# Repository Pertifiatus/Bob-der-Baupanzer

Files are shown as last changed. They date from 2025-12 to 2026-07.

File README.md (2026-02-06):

<h1 align="center">
  <br>
  🛠️ BOB DER BAUPANZER
  <br>
</h1>

<h3 align="center">
  <em>A remote controlled and tracked vehicle with a robotic arm</em>
</h3>
---

## What is Bob?

**Bob der Baupanzer** is a DIY-Roboticsprojekt: A remote controlled tracked vehicle with a controllable arm. It is controllable via ELRS and has 3 analog Cameras which you can change to.

---

## ✨ Features

<table>
<tr>
<td width="50%">

### ELRS
- Radiomaster Boxer Transmitter
- ExpressLRS 2.4GHz Protokoll
- Latency < 10ms

</td>
<td width="50%">

### Multi-Camera System
- 3 analog FPV-Cameras
- 3D-printed & Head tracked camera gimbal
- Front-, Arm- and 3rd Person Camera
- Reltime-Videofeed

</td>
</tr>
<tr>
<td width="50%">

### Robotic arm
- NEMA17 Stepper Motors
- Cycloid gear for high torque
- NEMA17 and NEMA14 controlled front
- Precise positioning

</td>
<td width="50%">

### Tracks
- 3D-printed Links
- Robust
- Steppermotor-driven

</td>
</tr>
</table>

---

## Hardware

### Electronics-overview

<p align="center">
  Electronics Bay
</p>

### 3D-Print Components

- **Chain-links** – Muodular design for easy assembly and quick repairs
- **Video System** – Head-tracked servo gimbal
- **Robotic-arm** – Joints, Holders, Pliers
- **Cablemanagement** – Sort of magnetic gridfinity for easy wireing

---
## 📸 Galery

<p align="center">
  Entwicklungs-Setup
  Greifer Detail
  Servo Montage
</p>

<p align="center">
  Test Setup
  Kettenantrieb
  Kamera Modul
</p>

---

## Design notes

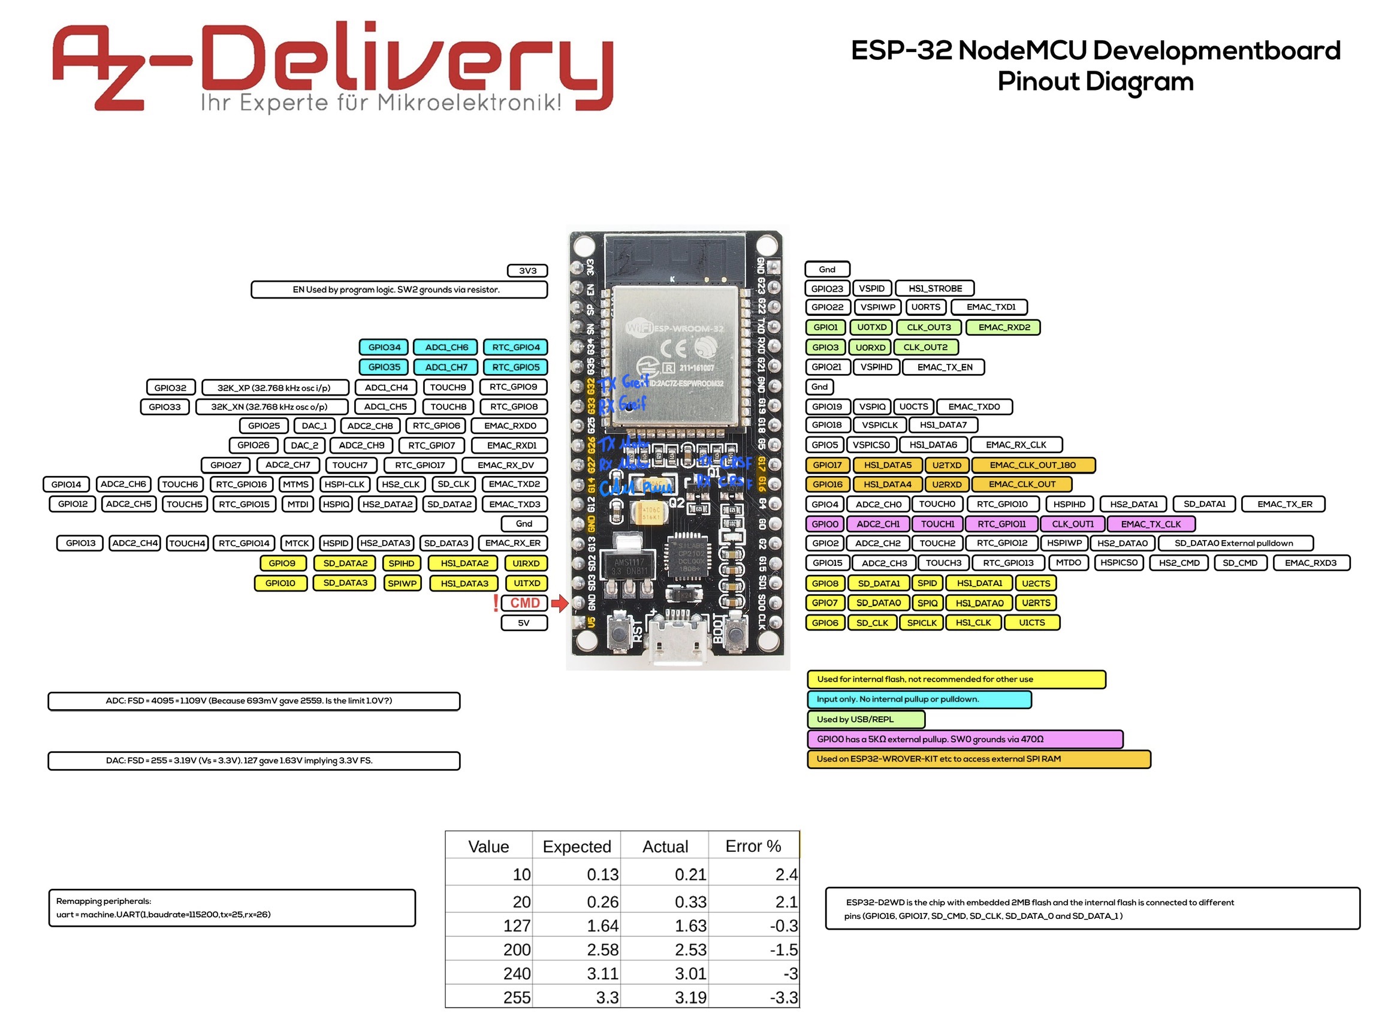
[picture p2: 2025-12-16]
Elektronik/Pinouts/ESP32-Pinout.jpg

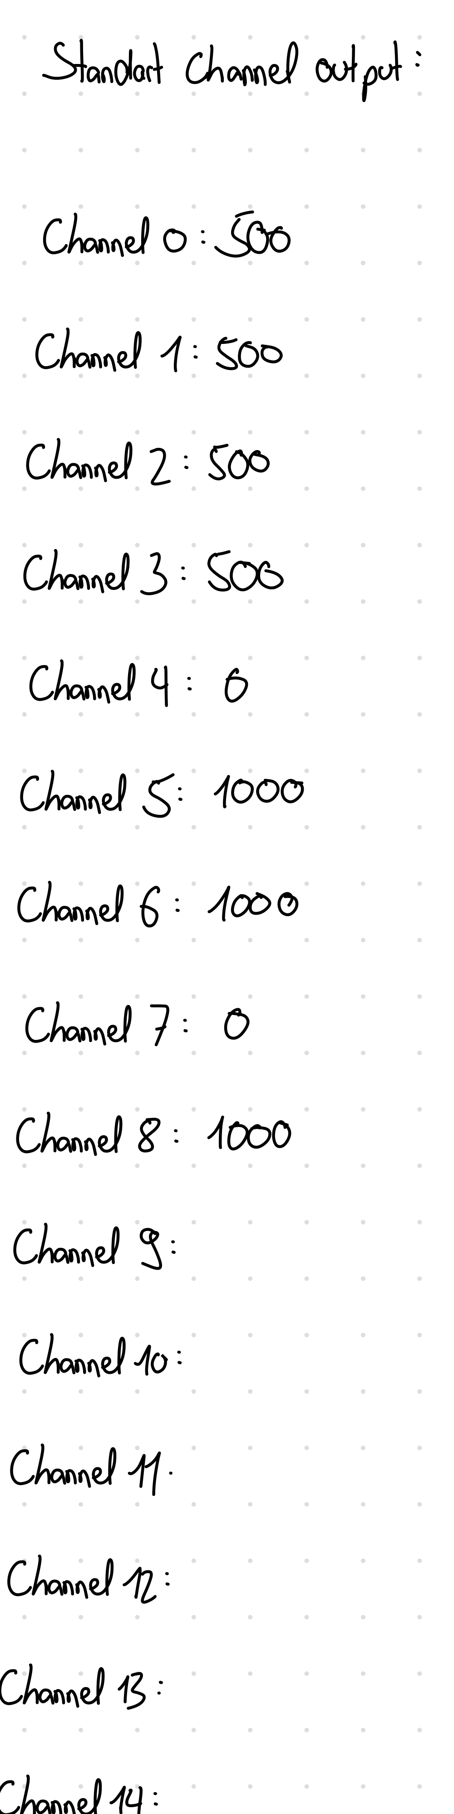
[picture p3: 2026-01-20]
Elektronik/Pinouts/PNG-Bild.png

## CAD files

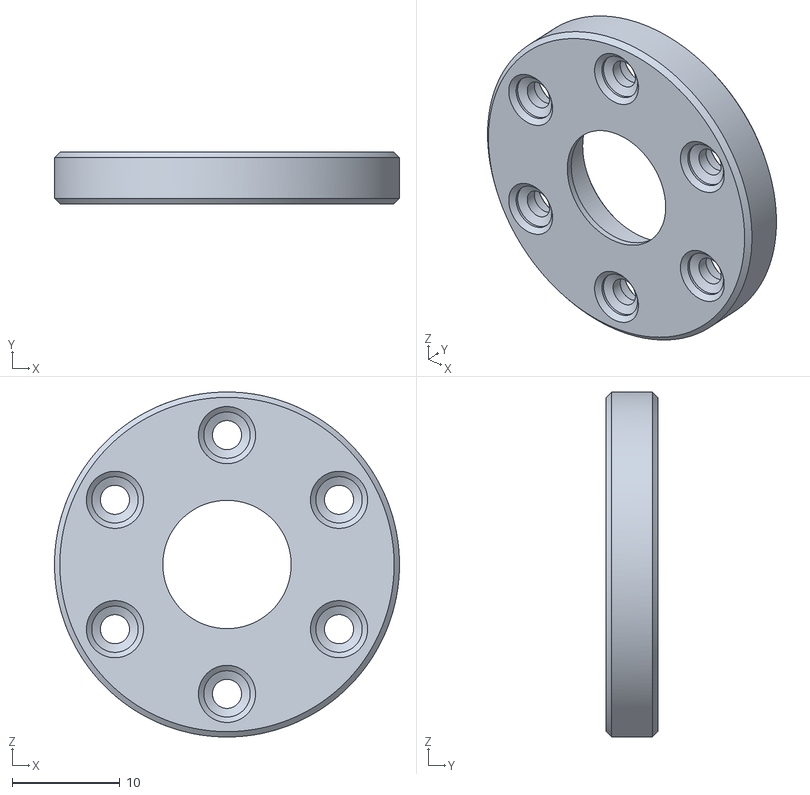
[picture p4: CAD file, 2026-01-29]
Greifarm/3dModels/Getriebe/Cycloidal 20;1/output_shaft_1--14.9.stl
32.0 x 4.80 x 32.0

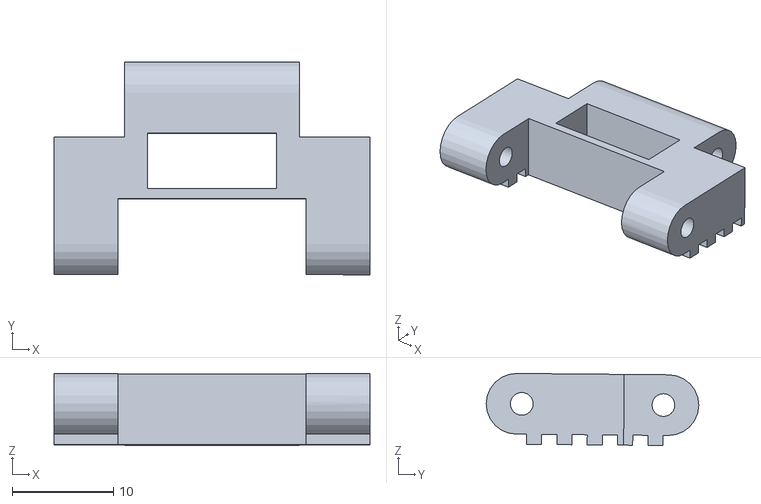
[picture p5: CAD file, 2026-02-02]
Greifarm/3dModels/Getriebe/Kette/Kette (50% Größe).STL
31.2 x 21.0 x 7.13

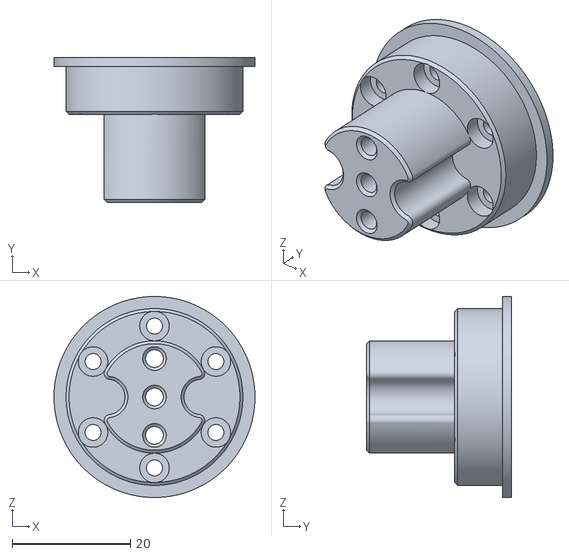
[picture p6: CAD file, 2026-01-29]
Greifarm/3dModels/Getriebe/Cycloidal 20;1/output_shaft_2--15_29.9.stl
34.0 x 24.5 x 34.0

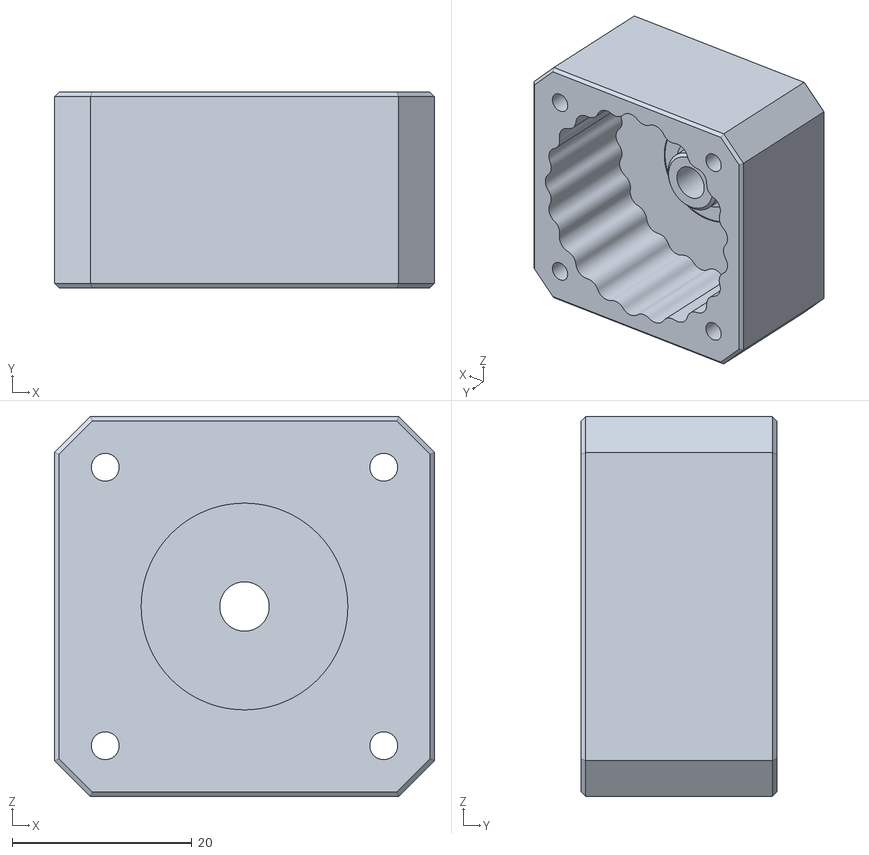
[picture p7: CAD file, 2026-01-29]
Greifarm/3dModels/Getriebe/Cycloidal 20;1/casing--9.9.stl
42.3 x 21.8 x 42.3

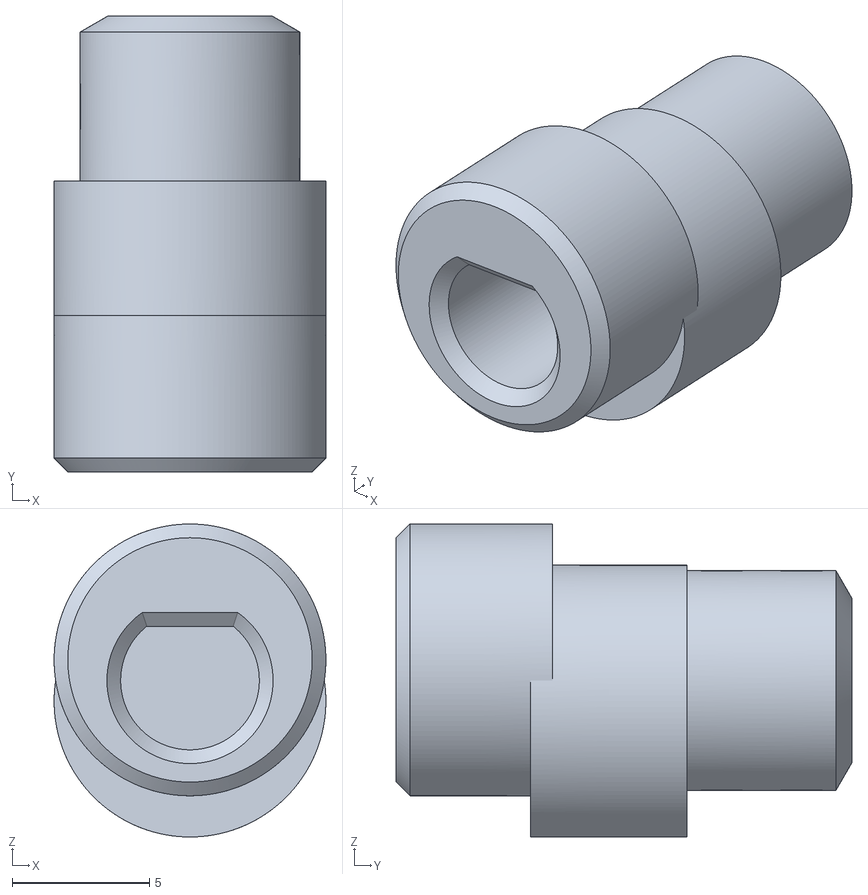
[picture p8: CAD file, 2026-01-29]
Greifarm/3dModels/Getriebe/Cycloidal 20;1/excentric_shaft--9.9.stl
9.90 x 16.6 x 11.4

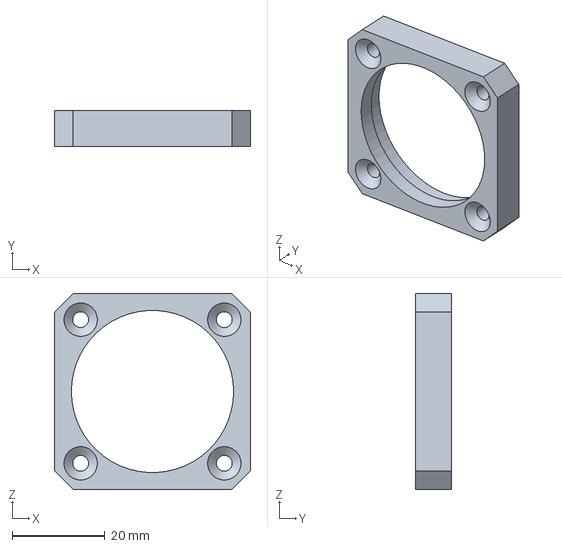
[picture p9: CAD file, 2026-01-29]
Greifarm/3dModels/Getriebe/Cycloidal 20;1/lid--36.9.stp
42.3 x 7.70 x 42.3 mm

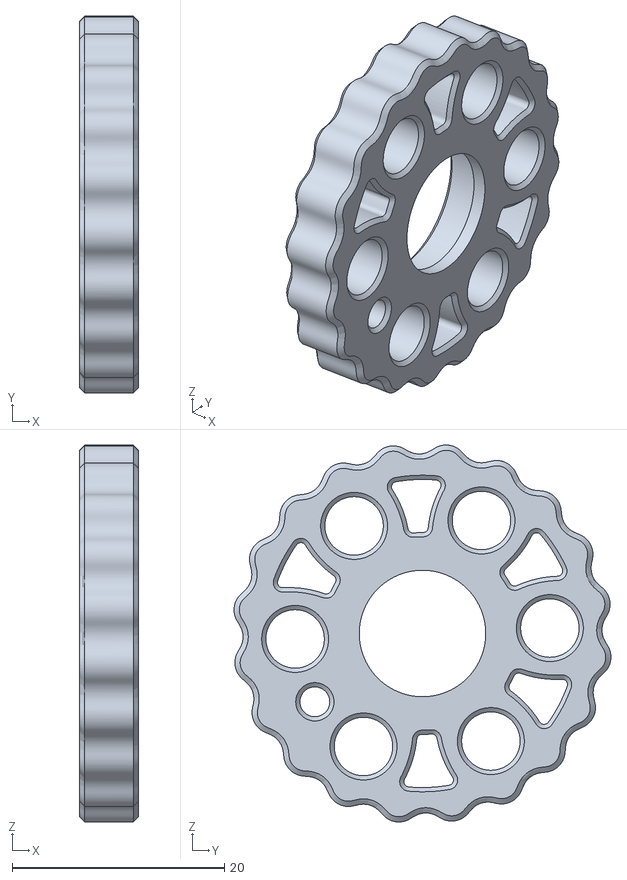
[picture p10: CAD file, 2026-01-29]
Greifarm/3dModels/Getriebe/Cycloidal 20;1/cycloidal_disk--5.5_14.9.stl
5.60 x 35.5 x 35.5

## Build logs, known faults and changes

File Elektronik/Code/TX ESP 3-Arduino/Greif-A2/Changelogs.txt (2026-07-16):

Greif-A2 Changelogs
===================

Greif-V3:
---------
- Erster vollständiger Sketch für den Greifarm-Arduino
- Startbyte 0xA2 für die Adressierung
- 8 Kanäle werden empfangen
- 4 Stepper-Motoren (X, Y, Z, A) mit AccelStepper
- "Grab" Modus eingeführt: Motoren laufen nur wenn CH4 aktiviert ist
- Enable-Steuerung über CH6
- CH7 als zusätzlicher Override zum Deaktivieren
- Failsafe mit allen Kanaelen auf 0 bzw. 1000
- Deadzone für alle 4 Achsen

Greif-V3-T0.2:
--------------
- Calibration-Funktion eingebaut! Beim Start muss man die Position kalibrieren
- "Calibrated" Flag um zu wissen ob kalibriert wurde
- Während Calibration kann man die Motoren bewegen um die Nullposition zu finden
- Calibration bestätigen mit CH4 < 500 und CH7 > 500
- Dann werden alle Stepper-Positionen auf 0 gesetzt
- vibrateMotor Funktion hinzugefügt (gibt haptisches Feedback bei Speichern)
- Failsafe-Werte auf 500 (Mittelstellung) geaendert
- Grab-Bedingung leicht angepasst (CH7 < 500 && CH4 > 500)

Greif-V4:
---------
- Stepper-Motoren sinnvoll umbenannt:
  * stepperX -> Drehachse1X
  * stepperY -> Gelenk2Y
  * stepperZ -> Gelenk3Z
  * stepperA -> Drehachse4A
- Acceleration für alle Motoren auf 2000 gesetzt (sanfteres Anfahren)
- vibrateMotor Funktion richtig implementiert (nicht mehr doppelt)
- Vibration bewegt Motor kurz hin und her als Feedback
- Calibration-Bug behoben (nur noch einmal definiert)

Greif-V4.1:
-----------
- Limit Settings für Motor X hinzugefügt

Greif-V4.2:
-----------
- Limit Settings für alle Motoren hinzugefügt
- Vibrate auch für StepperY hinzugefügt

Greif-V4.3:
-----------
- Limit Settings Bug behoben. 
- StepperCalib void hinzugefügt

Greif-V4.4:
-----------
- Individuelle Geschwindigkeitslimits und Deadzone Fix für alle Motoren

Greif-V5.3:
-----------
- Homing()-Funktion hinzugefügt (analog zur Zange, aber ohne Differenzial):
  bei CH7 > 500 und CH4 < 500 fahren alle vier Achsen einzeln mit eigener
  Homing-Geschwindigkeit (HomingSpeedX/Y/Z/A) zurueck auf Position 0, mit
  Bremszone kurz davor (nutzt die bestehenden BREMSZONE-Werte) und
  Toleranzband (HomingToleranz), in dem eine Achse als "daheim" gilt
- loop() ruft bei aktivem Homing() nicht mehr zusaetzlich Stepper() auf

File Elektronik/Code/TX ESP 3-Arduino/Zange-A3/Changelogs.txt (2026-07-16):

Zange-A3 Changelogs
===================

Zange-V0:
---------
- Minimal-Sketch nur zum Testen des Relais
- Pin 3 als Output
- Nach 5 Sekunden Verzoegerung wird das Relais eingeschaltet
- Sonst nix - nur zum Pruefen ob die Hardware funktioniert

Zange-V3:
---------
- Vollstaendiger Zangen-Sketch basierend auf Greif-Code
- Startbyte 0xA3 fuer Zangen-Adresse
- 8 Kanaele werden empfangen
- 4 Stepper-Motoren (X, Y, Z, A) wie beim Greifarm
- Grab-Bedingung: CH7 < 500 UND CH4 < 500 (beide Schalter druecken)
- Enable ueber CH6
- Failsafe auf 0/1000 Werte
- Deadzone fuer alle Achsen

Zange-V3-T0:
------------
- Calibration-Funktion eingebaut
- "Calib" Variable (0 = nicht kalibriert, 1 = kalibriert)
- Beim Start laeuft Calibration-Schleife
- Man kann Motoren bewegen und dann Position speichern
- Speichern mit CH4 > 500 und CH7 < 500
- Noch kein Feedback beim Speichern

Zange-V3-T0.1:
--------------
- Relais-Steuerung hinzugefuegt (Pin 3)
- 5 Sekunden Verzoegerung beim Start, dann Relais an
- "Relais AN" wird auf Serial ausgegeben
- vibrateMotor() Funktion fuer haptisches Feedback
- Calibration gibt jetzt "Calibration-Initiated" und "Calib-SAVE" aus
- Bei Speichern vibriert der Motor kurz zur Bestaetigung
- Debug-Ausgabe auch waehrend Calibration aktiv

Zange-V3-T0.2:
--------------
- Relais-Pin von 3 auf 2 geaendert
- "Calib" (int) zu "Calibrated" (bool) geaendert - sauberer Code
- Grab-Bedingung komplett geaendert: CH7 > 500 UND CH4 > 500
  (Jetzt muessen beide Schalter in die andere Richtung)
- Calibration-Bedingung angepasst: CH4 < 500 und CH7 > 500
- Override-Logik verbessert: CH6 > 500 und CH4 < 500 deaktiviert Motoren
- Failsafe-Werte auf 500 (Mittelstellung) geaendert statt 0
- Enable wird bei Calibration kurz aktiviert fuer die Vibration
- Mehr Kommentare im Code fuer bessere Lesbarkeit

Zange-V4:
--------------
- Endstops bei den 2 Kanälen hinzugefügt. 
- Die Schrittmotoren umbenannt

Zange-V4.1:
--------------
- StepperCalib hinzuefügt, sodass ich beim Calib keine Limits habe

Zange-V4.2:
--------------
Relais floating Pin bug gefixed

Zange-V5.4:
--------------
- Limits/Bremszonen umgestellt auf die logischen Kipp- und Greif-Achsen
  statt auf die rohen Motor-Positionen (Gelenk5X/Greifer6Y)
- Grund: Beide Motoren treiben zusammen ein Differenzial an, jeder
  Motorschritt ist eine Mischung aus Kipp- und Greif-Bewegung
  (X = Kipp+Greif, Y = -Kipp+Greif). Die alten Limits pro Motor haben
  dadurch nicht mehr die tatsaechliche Achsposition abgebildet.
- Kipp-Achse und Greif-Achse haben jetzt eigene LIMIT_MIN/MAX und
  BREMSZONE-Werte, die tatsaechliche Position wird per Differenzial-
  Kinematik aus beiden Motorpositionen zurueckgerechnet
- Homing()-Funktion vervollständigt: bei CH7 > 500 und CH4 < 500 fahren
  beide Achsen mit eigener Homing-Geschwindigkeit (HomingSpeedKipp/
  HomingSpeedGreif) zurueck auf Position 0, mit Bremszone kurz davor
  und Toleranzband (HomingToleranz), in dem die Achse als "daheim" gilt
- loop() ruft bei aktivem Homing() nicht mehr zusaetzlich Stepper() auf

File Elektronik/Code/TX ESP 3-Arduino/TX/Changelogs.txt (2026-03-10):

TX Changelogs
=============

TX-V0:
------
- Erster Test-Sketch für den TX-ESP32
- CRSF Library eingebunden für Crossfire-Empfaenger
- RX auf GPIO6, TX auf GPIO5
- Liest alle 16 Kanäle vom Empfänger
- Gibt alle Kanäle auf dem Serial Monitor aus
- TXSerial auf 9600 Baud (noch nicht benutzt)
- Nur zum Testen ob die CRSF-Verbindung funktioniert

TX-V1:
------
- Richtiges Kommunikations-Protokoll eingebaut!
- Verschiedene Start-Tokens für verschiedene Empfänger:
  * 0x01 für ESP32 (14 Kanäle)
  * 0xA1 für Arduino 1 - Motor (7 Kanäle)
  * 0xA2 für Arduino 2 - Greif (6 Kanäle)
  * 0xA3 für Arduino 3 - Zange (3 Kanäle)
- Alle 50ms wird an jeden Empfänger gesendet
- Werte werden von CRSF (172-1810) auf 0-1000 gemappt
- constrain() sorgt dafür dass Werte im Bereich bleiben
- TXSerial auf 115200 Baud, RX=20, TX=21

TX-V2:
------
- Kanal-Anzahl für A1 von 7 auf 6 reduziert
- Kanal-Anzahl für A2 von 6 auf 8 erhöht

TX-V3:
------
- Kanal-Anzahl für A3 von 3 auf 8 erhöht

TX-V4:
------
- "Failsave Modus" hinzugefügt, wenn alle Kanäle auf 0 sind, sendet der ESP keine Daten mehr an die Geräte, sodass diese in den    Failsave Modus gehen, anstatt alle Motoren schnell zu drehen

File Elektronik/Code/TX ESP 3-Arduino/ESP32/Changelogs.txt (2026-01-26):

ESP32 Changelogs
================

ESP32-V3:
---------
- Basis-Sketch für den ESP32 auf dem Fahrzeug
- Empfängt alle 14 Kanaele über Serial2 (RX=14, TX=27)
- Startbyte 0x01 für ESP32-Pakete
- Debug-Ausgabe alle 100ms auf Serial
- HeadTracker Funktion vorbereitet aber noch leer
- ESP32PWM Timer 0 reserviert

ESP32-V3.1:
-----------
- Head-Tracker implementiert!
- Zwei Servos hinzugefuegt: Pitch (Pin 25) und Sweep (Pin 26)
- Servos mit 500-2500us Pulsweite konfiguriert
- HeadTracker() Funktion liest Kanal 9 (Pitch) und Kanal 10 (Sweep)
- Werte werden von 0-1000 auf 0-180 Grad gemappt
- Debug-Intervall auf 200ms erhoeht

ESP32-V3.2:
-----------
- NeoPixel LED-Strip eingebaut! (10 LEDs an Pin 33)
- Adafruit_NeoPixel Library hinzugefuegt
- LEDs zeigen die aktuelle Sweep-Position an
  * Alle LEDs weiss, nur 3 LEDs an der aktuellen Position aus (als Positionsanzeige)
- Video-Switcher Servo an Pin 32 hinzugefuegt
- 3 Kamera-Positionen ueber CH8:
  * Position 1: 1000us
  * Position 2: 1500us
  * Position 3: 2000us
- Video() Funktion ersetzt HeadTracker() und macht beides
- LED Helligkeit auf 50 (von 255) eingestellt

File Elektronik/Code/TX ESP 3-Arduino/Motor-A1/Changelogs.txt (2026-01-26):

Motor-A1 Changelogs
===================

Motor-V1:
---------
- Erster Sketch für den Motor-Arduino
- Empfängt 7 Kanäle über Serial mit Startbyte 0xA1
- Gibt die empfangenen Werte einfach auf dem Serial Monitor aus
- Noch keine Motorsteuerung, nur zum Testen der Kommunikation

Motor-V2:
---------
- Failsafe eingebaut: Wenn 500ms keine Daten kommen, werden alle Kanäle auf 0 gesetzt
- Kanalanzahl auf 6 reduziert
- "MeineNachricht" Flag eingeführt - damit werden nur Pakete mit dem richtigen Startbyte verarbeitet
- Debug-Ausgabe läuft jetzt nur alle 100ms (schont die CPU)
- Zeigt an ob Daten empfangen werden [OK] oder Failsafe aktiv ist [!]

Motor-V3-ErsteMotor:
--------------------
- AccelStepper Library eingebunden für 4 Schrittmotoren (X, Y, Z, A)
- Enable-Pin (Pin 8) für die Treiber hinzugefuegt
- Deadzone-Funktion eingebaut damit kleine Stick-Bewegungen ignoriert werden
- Drive-Modus eingeführt: Motoren laufen nur wenn CH4 aktiviert ist
- Arming-Logik: Motoren werden automatisch aktiviert wenn die Sticks bewegt werden
- Failsafe-Werte jetzt auf Mittelstellung (500) statt 0
- Speed auf 1300 Steps/s eingestellt
- Debug-Ausgabe auskommentiert (für Performance)

Motor-V3.1:
-----------
- Keine Änderungen zu V3-ErsteMotor
- Nur aufgeräumte Version ohne zusätzliche Leerzeilen

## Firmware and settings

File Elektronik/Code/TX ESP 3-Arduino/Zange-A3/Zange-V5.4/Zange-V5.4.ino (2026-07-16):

#include <AccelStepper.h>

#define ENABLE_PIN 8
int EN = 1;    // 0=Enabled, 1=Disabled
int Grab = 0;  // Grab Status
long speedX = 0;
long speedY = 0;
long speedKipp = 0;
long speedGreif = 0;

const long MaxSpeedKipp = 600;    //SPEED... I am SPEED... Faster than fast quicker than quick... I am lightning
const long MaxSpeedGreif = 7000;  //SPEED... I am SPEED... Faster than fast quicker than quick... I am lightning
const long MaxSpeedMotor = MaxSpeedKipp + MaxSpeedGreif;  // Motor sieht im schlechtesten Fall die Summe beider Anteile

// Beide Motoren treiben zusammen ein Differenzial an: jeder Motorschritt ist eine
// Mischung aus Kipp- und Greif-Bewegung (X = Kipp+Greif, Y = -Kipp+Greif). Deshalb
// werden die Limits hier auf die zurueckgerechneten logischen Achsen angewendet und
// nicht mehr auf die rohen Motor-Positionen.
const long LIMIT_MIN_Kipp = -900;
const long LIMIT_MAX_Kipp = 900;
const long BREMSZONE_Kipp = 200;

const long LIMIT_MIN_Greif = -35000;
const long LIMIT_MAX_Greif = 10000;
const long BREMSZONE_Greif = 1000;

// Geschwindigkeiten fuers Homing (langsamer als der normale Betrieb) sowie die
// Toleranz, ab der eine Achse als "daheim" (Position 0) gilt.
const long HomingSpeedKipp = 300;
const long HomingSpeedGreif = 2000;
const long HomingToleranz = 5;

AccelStepper Gelenk5X(AccelStepper::DRIVER, 2, 5);
AccelStepper Greifer6Y(AccelStepper::DRIVER, 3, 6);

int applyDeadzone(int value, int dz) {
  return (abs(value) < dz) ? 0 : value;
}

const byte ST = 0xA3;
const int NUM_CHANNELS = 8;
int channels[NUM_CHANNELS];

unsigned long lastPacketTime = 0;
const unsigned long TimeoutFailsafe = 500;
bool failsafeActive = false;
bool Calibrated = false;

// Binärprotokoll: pro Kanal 2 Bytes (low/high, je auf 7 Bit begrenzt), damit
// alle Nutzdaten-Bytes < 0x80 bleiben - nur die Start-Bytes der Boards
// (0xA0-0xA3) haben Bit 7 gesetzt und sind so immer eindeutig vom Kanalwert
// zu unterscheiden. Dadurch ist die Frame-Länge konstant, egal ob die Kanäle
// bei 0 oder bei 1000 stehen.
const int FRAME_PAYLOAD_LEN = NUM_CHANNELS * 2;
byte frameBuffer[FRAME_PAYLOAD_LEN];
int frameIndex = 0;
bool receivingFrame = false;


void setup() {
  pinMode(4, OUTPUT);  //Relais Pin
  digitalWrite(4, 0);
  pinMode(ENABLE_PIN, OUTPUT);
  Gelenk5X.setMaxSpeed(MaxSpeedMotor);
  Gelenk5X.setAcceleration(2000);
  Greifer6Y.setMaxSpeed(MaxSpeedMotor);
  Greifer6Y.setAcceleration(2000);

  Serial.begin(250000);

  activateFailsafe();
  lastPacketTime = millis();

  delay(5000);
  digitalWrite(4, 1);
  Serial.println("Relais AN");

  Calibration();
}

void Calibration() {
  Serial.print("Calibration-Initiated");
  while (!Calibrated) {
    ReadSerial();
    static unsigned long lastDebugTime = 0;

    if (millis() - lastDebugTime > 100) {  // Nur alle 100ms Text ausgeben
      lastDebugTime = millis();
      printDebugInfo();
    }

    if (channels[4] < 500 && channels[7] > 500) {
      Gelenk5X.setCurrentPosition(0);
      Greifer6Y.setCurrentPosition(0);
      Calibrated = true;
      digitalWrite(ENABLE_PIN, 0);
      vibrateMotor(Gelenk5X, 20, 2);
      digitalWrite(ENABLE_PIN, 1);
      Serial.print("Calib-SAVE");
    } else {
      Channellogic();
      StepperCalib();
    }
  }
}

void loop() {
  ReadSerial();
  Channellogic();
  if (!Homing()) {
    Stepper();
  }
  /*
  static unsigned long lastDebugTime = 0;
  if (millis() - lastDebugTime > 100) {  // Nur alle 100ms Text ausgeben (schont die CPU)
    lastDebugTime = millis();
    printDebugInfo();
  }
  */
}


void ReadSerial() {
  while (Serial.available() > 0) {  //Wenn Serielle Daten verfügbar sind
    byte incomingByte = Serial.read();

    if (incomingByte == ST) {  //Falls unser Startbyte erkannt wird: neuen Frame beginnen
      receivingFrame = true;
      frameIndex = 0;
      continue;
    }

    if (incomingByte & 0x80) {
      // Startbyte eines anderen Boards -> unser Frame ist ungültig/beendet
      receivingFrame = false;
      continue;
    }

    if (!receivingFrame) continue;

    if (frameIndex < FRAME_PAYLOAD_LEN) {
      frameBuffer[frameIndex++] = incomingByte;
    } else {
      // Dieses Byte ist die Prüfsumme -> Frame ist komplett
      decodeFrame(incomingByte);
      receivingFrame = false;
    }
  }

  //  Failsafe Check
  if (millis() - lastPacketTime > TimeoutFailsafe) {
    if (!failsafeActive) {
      activateFailsafe();
      failsafeActive = true;
    }
  }
}

// Prüft die Prüfsumme und übernimmt bei Erfolg die Kanalwerte aus frameBuffer.
void decodeFrame(byte receivedChecksum) {
  byte checksum = 0;
  for (int i = 0; i < FRAME_PAYLOAD_LEN; i++) checksum ^= frameBuffer[i];
  checksum &= 0x7F;

  if (checksum != receivedChecksum) {
    // Frame verwerfen, da Prüfsumme nicht passt (z.B. durch Bitfehler)
    return;
  }

  // Die XOR-Prüfsumme erkennt nicht jeden Bitfehler (z.B. zwei Bitkipper an
  // derselben Position in unterschiedlichen Bytes können sich gegenseitig
  // aufheben). Als zweite Verteidigungslinie werden die dekodierten Werte
  // zusätzlich auf den gültigen Bereich 0-1000 begrenzt, damit ein durch die
  // Prüfsumme rutschender Fehler keinen Kanalwert weit außerhalb des
  // erwarteten Bereichs an die Motorsteuerung weiterreichen kann.
  for (int i = 0; i < NUM_CHANNELS; i++) {
    byte lowBits = frameBuffer[i * 2];
    byte highBits = frameBuffer[i * 2 + 1];
    channels[i] = constrain(lowBits | (highBits << 7), 0, 1000);
  }

  // Wenn Daten korrekt ankommen -> Failsafe beenden
  if (failsafeActive) {
    failsafeActive = false;
  }
  lastPacketTime = millis();  //  Timeout-Timer erneuern
}

void activateFailsafe() {

  channels[0] = 500;
  channels[1] = 500;
  channels[2] = 500;
  channels[3] = 500;
  channels[4] = 0;
  channels[5] = 1000;
  channels[6] = 1000;
  channels[7] = 0;
}

void printDebugInfo() {
  if (failsafeActive) {
    Serial.print(" [!] - Fallback: ");
  } else {
    Serial.print(" [OK] - Werte: ");
  }

  for (int i = 0; i < NUM_CHANNELS; i++) {
    Serial.print(channels[i]);
    if (i < NUM_CHANNELS - 1) Serial.print(",");
  }
  Serial.print(Grab);
  Serial.println();
}

void Channellogic() {
  long kippAnteil = map(channels[1], 0, 1000, MaxSpeedKipp, -MaxSpeedKipp);
  long greifAnteil = map(channels[2], 0, 1000, MaxSpeedGreif, -MaxSpeedGreif);

  kippAnteil = applyDeadzone(kippAnteil, MaxSpeedKipp * 0.1);
  greifAnteil = applyDeadzone(greifAnteil, MaxSpeedGreif * 0.1);

  speedKipp = kippAnteil;
  speedGreif = greifAnteil;

  speedX = kippAnteil + greifAnteil;
  speedY = -kippAnteil + greifAnteil;

  // Logik für Enable (EN)
  if (channels[6] < 500) {  //Falls Channel 6 kleiner 500 ist
    EN = 0;                 // Motor AN
  } else {
    EN = 1;  // Motor AUS
  }


  if (channels[7] > 500 && channels[4] > 500) {  //Falls Channel 7 großer 500, und Channel 4 großer 500. (Beide Switches gedrückt)
    Grab = 1;
  } else {
    Grab = 0;
  }

  if (Grab == 1) {  // Arming in Grab Action
    if (speedX != 0 || speedY != 0) {
      EN = 0;  // Wenn die Sticks nicht center sind, Motor AN
    }
  }

  if (channels[6] > 500 && channels[4] < 500) {  // Override, falls Channel gewechselt wird, während sich die Motoren drehen
    EN = 1;
  }
}

void Stepper() {
  if (Grab == 1) {
    long currentPosX = Gelenk5X.currentPosition();
    long currentPosY = Greifer6Y.currentPosition();

    // Differenzial-Kinematik umkehren (X = Kipp+Greif, Y = -Kipp+Greif), um die
    // tatsaechliche Position der beiden logischen Achsen zu bestimmen.
    long kippPos = (currentPosX - currentPosY) / 2;
    long greifPos = (currentPosX + currentPosY) / 2;

    long finalKipp = speedKipp;
    long finalGreif = speedGreif;

    //Bremszone Kipp
    if (finalKipp > 0 && (LIMIT_MAX_Kipp - kippPos) < BREMSZONE_Kipp) {
      // Bremse Richtung Plus
      finalKipp = finalKipp * (LIMIT_MAX_Kipp - kippPos) / BREMSZONE_Kipp;

    } else if (finalKipp < 0 && (kippPos - LIMIT_MIN_Kipp) < BREMSZONE_Kipp) {
      // Bremse Richtung Minus
      finalKipp = finalKipp * (kippPos - LIMIT_MIN_Kipp) / BREMSZONE_Kipp;
    }

    // Not-Stopp Sicherheitscheck
    if (kippPos >= LIMIT_MAX_Kipp && finalKipp > 0) finalKipp = 0;
    if (kippPos <= LIMIT_MIN_Kipp && finalKipp < 0) finalKipp = 0;

    //Bremszone Greif
    if (finalGreif > 0 && (LIMIT_MAX_Greif - greifPos) < BREMSZONE_Greif) {
      // Bremse Richtung Plus
      finalGreif = finalGreif * (LIMIT_MAX_Greif - greifPos) / BREMSZONE_Greif;

    } else if (finalGreif < 0 && (greifPos - LIMIT_MIN_Greif) < BREMSZONE_Greif) {
      // Bremse Richtung Minus
      finalGreif = finalGreif * (greifPos - LIMIT_MIN_Greif) / BREMSZONE_Greif;
    }

    // Not-Stopp Sicherheitscheck
    if (greifPos >= LIMIT_MAX_Greif && finalGreif > 0) finalGreif = 0;
    if (greifPos <= LIMIT_MIN_Greif && finalGreif < 0) finalGreif = 0;

    // Zurueck in die tatsaechlichen Motor-Geschwindigkeiten wandeln
    Gelenk5X.setSpeed(finalKipp + finalGreif);
    Greifer6Y.setSpeed(-finalKipp + finalGreif);

  } else {
    Gelenk5X.setSpeed(0);
    Greifer6Y.setSpeed(0);
  }
  digitalWrite(ENABLE_PIN, EN);
  Gelenk5X.runSpeed();
  Greifer6Y.runSpeed();
}

// Faehrt beide Achsen mit fester Homing-Geschwindigkeit Richtung 0 (Ursprungslage).
// Gibt true zurueck, waehrend Homing aktiv ist - Stepper() darf dann in diesem
// Zyklus nicht zusaetzlich auf die Motoren schreiben.
bool Homing() {
  if (!(channels[7] > 500 && channels[4] < 500)) return false;

  long currentPosX = Gelenk5X.currentPosition();
  long currentPosY = Greifer6Y.currentPosition();

  // Differenzial-Kinematik umkehren, um die logische Achsposition zu bestimmen.
  long kippPos = (currentPosX - currentPosY) / 2;
  long greifPos = (currentPosX + currentPosY) / 2;

  long homeKipp = 0;
  if (kippPos > HomingToleranz) {
    homeKipp = -HomingSpeedKipp;
    if (kippPos < BREMSZONE_Kipp) homeKipp = homeKipp * kippPos / BREMSZONE_Kipp;
  } else if (kippPos < -HomingToleranz) {
    homeKipp = HomingSpeedKipp;
    if (-kippPos < BREMSZONE_Kipp) homeKipp = homeKipp * -kippPos / BREMSZONE_Kipp;
  }

  long homeGreif = 0;
  if (greifPos > HomingToleranz) {
    homeGreif = -HomingSpeedGreif;
    if (greifPos < BREMSZONE_Greif) homeGreif = homeGreif * greifPos / BREMSZONE_Greif;
  } else if (greifPos < -HomingToleranz) {
    homeGreif = HomingSpeedGreif;
    if (-greifPos < BREMSZONE_Greif) homeGreif = homeGreif * -greifPos / BREMSZONE_Greif;
  }

  digitalWrite(ENABLE_PIN, 0);  // Motoren fuers Homing aktivieren, unabhaengig von EN
  Gelenk5X.setSpeed(homeKipp + homeGreif);
  Greifer6Y.setSpeed(-homeKipp + homeGreif);
  Gelenk5X.runSpeed();
  Greifer6Y.runSpeed();

  return true;
}


void StepperCalib() {

  if (Grab == 1) {
    Gelenk5X.setSpeed(speedX);
    Greifer6Y.setSpeed(speedY);

  } else {
    Gelenk5X.setSpeed(0);
    Greifer6Y.setSpeed(0);
  }
  digitalWrite(ENABLE_PIN, EN);
  Gelenk5X.runSpeed();
  Greifer6Y.runSpeed();
}

void vibrateMotor(AccelStepper &stepper, int intensity, int pulses) {

  long originalPos = stepper.currentPosition();

  for (int i = 0; i < pulses; i++) {
    stepper.moveTo(originalPos + intensity);
    while (stepper.distanceToGo() != 0) stepper.run();
    stepper.moveTo(originalPos - intensity);
    while (stepper.distanceToGo() != 0) stepper.run();
  }
  stepper.moveTo(originalPos);
  while (stepper.distanceToGo() != 0) stepper.run();
}

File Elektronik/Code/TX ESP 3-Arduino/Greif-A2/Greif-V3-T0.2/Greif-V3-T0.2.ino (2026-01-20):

#include <AccelStepper.h>

#define ENABLE_PIN 8
#define SPEED 1300  //SPEED... I am SPEED... Faster than fast quicker than quick... I am lightning
int EN = 1;         // 0=Enabled, 1=Disabled
int Grab = 0;       // Grab Status
long speedX = 0;
long speedY = 0;
long speedZ = 0;
long speedA = 0;

AccelStepper stepperX(AccelStepper::DRIVER, 2, 5);
AccelStepper stepperY(AccelStepper::DRIVER, 3, 6);
AccelStepper stepperZ(AccelStepper::DRIVER, 4, 7);
AccelStepper stepperA(AccelStepper::DRIVER, 12, 13);
int applyDeadzone(int value, int dz) {
  return (abs(value) < dz) ? 0 : value;
}

const byte ST = 0xA2;
const int NUM_CHANNELS = 8;
int channels[NUM_CHANNELS];
String input = "";

unsigned long lastPacketTime = 0;
const unsigned long TimeoutFailsafe = 500;
bool failsafeActive = false;
bool MeineNachricht = false;
bool Calibrated = false;

void setup() {
  pinMode(ENABLE_PIN, OUTPUT);
  stepperX.setMaxSpeed(SPEED);
  stepperY.setMaxSpeed(SPEED);
  stepperZ.setMaxSpeed(SPEED);
  stepperA.setMaxSpeed(SPEED);


  Serial.begin(115200);
  input.reserve(50);

  activateFailsafe();
  lastPacketTime = millis();

  Calibration();
}

void Calibration() {
  Serial.print("Calibration-Initiated");
  while (!Calibrated) {
    ReadSerial();
    static unsigned long lastDebugTime = 0;

    if (millis() - lastDebugTime > 100) {  // Nur alle 100ms Text ausgeben (schont die CPU)
      lastDebugTime = millis();
      printDebugInfo();
    }

    if (channels[4] < 500 && channels[7] > 500) {
      stepperA.setCurrentPosition(0);
      stepperZ.setCurrentPosition(0);
      stepperY.setCurrentPosition(0);
      stepperX.setCurrentPosition(0);
      Calibrated = true;
      digitalWrite(ENABLE_PIN, 0);
      vibrateMotor(stepperX, 10, 2);
      digitalWrite(ENABLE_PIN, 1);
      Serial.print("Calib-SAVE");
    } else {
      Channellogic();
      Stepper();
    }
  }
}
void loop() {
  ReadSerial();
  Channellogic();
  Stepper();

  /*
	static unsigned long lastDebugTime = 0;
  if (millis() - lastDebugTime > 100) {  // Nur alle 100ms Text ausgeben (schont die CPU)
    lastDebugTime = millis();
    printDebugInfo();
  }
	*/
}


void ReadSerial() {
  while (Serial.available() > 0) {  //Wenn Serielle Daten verfügbar sind
    byte incomingByte = Serial.read();

    if (incomingByte == ST) {  //Falls Startbyte erkannt wird: input zurücksetzen
      input = "";
      MeineNachricht = true;  //Setze die MeineNachricht Variable auf True
    } else if (incomingByte > 0x80) {
      MeineNachricht = false;
    }

    else if (MeineNachricht) {
      if (incomingByte == '\n') {
        parseBuffer();
        MeineNachricht = false;
        break;
      } else {
        input += (char)incomingByte;
      }
    }
  }

  //  Failsafe Check
  if (millis() - lastPacketTime > TimeoutFailsafe) {
    if (!failsafeActive) {
      activateFailsafe();
      failsafeActive = true;
    }
  }
}

void parseBuffer() {
  int n = sscanf(input.c_str(), "%d,%d,%d,%d,%d,%d,%d,%d",
                 &channels[0], &channels[1], &channels[2],
                 &channels[3], &channels[4], &channels[5],
                 &channels[6], &channels[7]);

  if (n == NUM_CHANNELS) {
    // Wenn Daten korrekt ankommen -> Failsafe beenden
    if (failsafeActive) {
      failsafeActive = false;
    }
    lastPacketTime = millis();  // Zeitstempel für Timeout-Timer erneuern
  }
}

void activateFailsafe() {

  channels[0] = 500;
  channels[1] = 500;
  channels[2] = 500;
  channels[3] = 500;
  channels[4] = 0;
  channels[5] = 1000;
  channels[6] = 1000;
  channels[7] = 0;
}

void printDebugInfo() {
  if (failsafeActive) {
    Serial.print(" [!] - Fallback: ");
  } else {
    Serial.print(" [OK] - Werte: ");
  }

  for (int i = 0; i < NUM_CHANNELS; i++) {
    Serial.print(channels[i]);
    if (i < NUM_CHANNELS - 1) Serial.print(",");
  }
  Serial.print(Grab);
  Serial.println();
}

void Channellogic() {
  speedX = map(channels[0], 0, 1000, -SPEED, SPEED);
  speedX = applyDeadzone(speedX, 200);


  speedY = map(channels[1], 0, 1000, -SPEED, SPEED);
  speedY = applyDeadzone(speedY, 100);

  speedZ = map(channels[2], 0, 1000, -SPEED, SPEED);
  speedZ = applyDeadzone(speedZ, 200);


  speedA = map(channels[3], 0, 1000, -SPEED, SPEED);
  speedA = applyDeadzone(speedA, 100);

  // Logik für Enable (EN)
  if (channels[6] < 500) {
    EN = 0;  // Motor AN
  } else {
    EN = 1;  // Motor AUS
  }

  if (channels[7] < 500 && channels[4] > 500) {
    Grab = 1;
  } else {
    Grab = 0;
  }

  if (Grab == 1) {  // Arming in Grab Action
    if (speedX != 0 || speedY != 0 || speedZ != 0 || speedA != 0) {
      EN = 0;  // Wenn die Sticks nicht center sind, Motor AN
    }
  }
  if (channels[6] > 500 && channels[4] > 500) {  // Automatischer Override
    EN = 1;
  }
}

void Stepper() {

  if (Grab == 1) {
    stepperX.setSpeed(speedX);
    stepperY.setSpeed(speedY);
    stepperZ.setSpeed(speedZ);
    stepperA.setSpeed(speedA);
  } else {
    stepperX.setSpeed(0);
    stepperY.setSpeed(0);
    stepperZ.setSpeed(0);
    stepperA.setSpeed(0);
  }
  digitalWrite(ENABLE_PIN, EN);
  stepperX.runSpeed();
  stepperY.runSpeed();
  stepperZ.runSpeed();
  stepperA.runSpeed();
}

void Calibration() {
  Serial.print("Calibration-Initiated");
  while (!Calibrated) {
    ReadSerial();
    static unsigned long lastDebugTime = 0;

    if (millis() - lastDebugTime > 100) {  // Nur alle 100ms Text ausgeben (schont die CPU)
      lastDebugTime = millis();
      printDebugInfo();
    }

    if (channels[4] < 500 && channels[7] > 500) {
      stepperA.setCurrentPosition(0);
      stepperZ.setCurrentPosition(0);
      stepperY.setCurrentPosition(0);
      stepperX.setCurrentPosition(0);
      Calibrated = true;
      digitalWrite(ENABLE_PIN, 0);
      vibrateMotor(stepperX, 10, 2);
      digitalWrite(ENABLE_PIN, 1);
      Serial.print("Calib-SAVE");
    } else {
      Channellogic();
      Stepper();
    }
  }
}

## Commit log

2025-12-16 Motor Läuft-1
2025-12-16 Remove commented text from Arduino file
2025-12-16 Remove acceleration settings for stepper motors
2025-12-18 Reduced code (#4)
    * Clean up Test-7.ino by removing comments
    Removed commented-out serial print statement and adjusted formatting.
    * Add files via upload
    * Rename Test-7.ino.txt to Test-7.1.ino
    * Refactor motor control and add stepperZ support
    Updated motor control logic and added stepperZ functionality.
    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
2025-12-18 Refactor stepper control and reading functions
2025-12-18 Fix AccelStepper driver type for stepperZ
    [Test-7.1.ino]
2025-12-18 Refactor motor control logic in Test-7.1.ino
2025-12-18 Fix indentation in conditional statement
    [Test-7.1.ino]
2025-12-18 Fix indentation and formatting in Test-7.1.ino
    [Test-7.1.ino]
2025-12-18 Clean up comments in Test-7.1.ino
    Removed unnecessary comments about updating stepper speed and enable pin.
2025-12-18 Fix deadzone application for X and Y axes
    [Test-7.1.ino]
2025-12-23 Refactor code structure and add CRSF library
    Moved multiple .ino files into dedicated subfolders for better organization. Added CRSF.cpp and CRSF.h library files to several test and library directories, implementing Crossfire RC channel decodin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
2025-12-30 Added and Modified Filed
    Added Pinout for Seeed Studio ESP32 C3 and modified the CRSF Test to fit to the Pinout. Added Modified Version of Test-7.1, with better overview of the code, and faster running speed
2025-12-31 Motor Sketch
    Added working Motor Sketch.
    Fixed Deadzone Funktion
    Added Failsafe Mode
    Fixed Bugs with Adress
    [Motor-V3-ErsteMotor.ino]
2026-01-01 Modified Files and Added Support for Greif Arduino
2026-01-02 Added Schaltplan and ESP Version
    Added ESP Code, to receive the Signals
    Added Schaltplan in Fritzing
    [Schaltplan.fzz]
2026-01-12 ESP32-V3.2.ino Adafruit Led namen geändert
2026-01-12 ESP32-V3.2.ino aktualisieren
2026-01-19 Added Calibration loop
2026-01-19 Add vibrateMotors function for motor control
    Implemented a function to vibrate motors with adjustable duration and speed.
2026-01-19 Add vibrateMotor function for motor control
    Implemented a function to vibrate a motor with specified intensity and pulse count.
2026-01-20 Greif aktualisieren, und Calib hinzufügen
2026-01-20 Motor-V3-ErsteMotor.ino aktualisieren
2026-01-20 Improve calibration and channel logic for stepper control
    Refined the calibration process by adding enable pin toggling during calibration and improved channel logic for more accurate motor control. Adjusted conditions for automatic override and arming, and fixed code formatting for better readability.
    [Greif-V3-T0.2.ino, Zange-V3-T0.2.ino]
2026-01-26 Add changelogs and new versions for Arduino modules
    Added changelog files and new versioned .ino files for ESP32, Greif-A2, Motor-A1, TX, and Zange-A3 modules. Updated Greif-V3-T0.2 and Greif-V4 to improve calibration logic and refactor stepper motor 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
2026-01-27 Rename Elektronik/Code/TX ESP 3-Arduino/Zange-A3/Zange-V4.1.ino to Elektronik/Code/TX ESP 3-Arduino/Zange-A3/Zange-V4.1/Zange-V4.1.ino
2026-01-27 Added Fix for Calib
    [Greif-V4.3.ino]
2026-01-27 Rename Elektronik/Code/TX ESP 3-Arduino/Greif-A2/Greif-V4.3.ino to Elektronik/Code/TX ESP 3-Arduino/Greif-A2/Greif-V4.3/Greif-V4.3.ino
2026-01-29 3D datten für Cycloidal Getriebe hinzugefügt
    [casing--9.9.stl, cycloidal_disk--5.5_14.9.stl, excentric_shaft--9.9.stl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]
2026-02-02 Added 3d Models
    [Kette (50% Größe).STL, output_shaft_2--15_29.8.stl]
2026-03-10 Add Zange-V4.2 Arduino code for motor control
2026-03-26 Rename Elektronik/Code/TX ESP 3-Arduino/Greif-A2/Greif-V4.4.ino to Elektronik/Code/TX ESP 3-Arduino/Greif-A2/Greif-V4.4/Greif-V4.4.ino
2026-03-26 Rename Elektronik/Code/TX ESP 3-Arduino/Zange-A3/Zange-V4.3.ino to Elektronik/Code/TX ESP 3-Arduino/Zange-A3/Zange-V4.3/Zange-V4.3.ino
2026-07-03 Changes and Transfer from Stepper Motors to Brushless
    Changed the Speed Values in Greif and Created Motor-V5 for controlling Brushless ESC
2026-07-10 Switch channel telemetry to a fixed-size binary frame (V5.1) (#5)
    The ASCII CSV protocol encoded each channel value as a variable number
    of digits, so the frame length (and thus total bus traffic across all
    four boards sharing the line) scaled with channel magnitude. At high
    values this overran the ESP32 receiver's 50-byte String reservation,
    forcing repeated heap reallocations right as the shared UART line was
    also busiest, causing dropped/corrupted frames - visible as the LCD's
    Pk/s counter dropping from ~21 to ~7 when all channels were maxed out.
    V5.1 replaces the CSV frame with a fixed-size binary one: each channel
    is split into two 7-bit bytes (keeping every payload byte below 0x80,
    so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
    [TX-V5.1.ino]
2026-07-16 Added Homing function
2026-07-16 Homing für Greif
2026-10-04 Expand README with Trello board info and project photos
2026-10-16 TX-V5.2: CRSF-Library mit Sync, CRC8, Link-Statistik und Timeout-Failsafe (#6)
2026-10-22 Clarify sendChannelFrame function comments
    Updated comments for clarity regarding channel frame format.
2026-11-05 added Motor codes for reading rpm
2026-11-06 added V5.3 for controll with Sensores
    Added codes for both sides to controll the DC Motors with Sensores
2026-11-07 Moved 3d Models and added Regler
    Moved 3d Models to another location and added codes for Regulating with P, I, PI, PID Codes
